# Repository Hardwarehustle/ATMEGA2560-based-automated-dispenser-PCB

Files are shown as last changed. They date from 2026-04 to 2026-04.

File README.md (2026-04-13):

# 💊 Automated Dispenser — ATMEGA2560 Based Smart Dispensing Controller PCB

> **Designed by:** Janardhan BV  
> **Tool:** EasyEDA  
> **MCU:** ATMEGA2560-16AU  
> **Date:** November 2024 | **Rev:** 1.0  
---

## 📌 Project Overview

This project is a **full-featured automated dispenser controller PCB** built around the **ATMEGA2560-16AU** (Arduino Mega 2560 compatible) microcontroller. The board is designed to drive **3 stepper motors** and **1 servo motor** for precise dispensing operations, with intelligent scheduling via a **real-time clock (RTC)**, remote alerting via a **SIM800L GSM module**, presence detection via an **IR sensor**, a **buzzer** for audio feedback, and an **I2C LCD display** for real-time status.

The system is ideal for **medicine dispensers, food dispensers, automated vending mechanisms**, or any time-triggered multi-compartment dispensing application.

The design covers:
- Full **schematic capture** in EasyEDA (ATMEGA2560-16AU + CH340G + all peripherals)
- **Multi-layer PCB layout** with 4x stepper/servo motor drives
- **GSM-based remote notification/control** via SIM800L
- **RTC-based scheduling** for timed dispensing events
- **Comprehensive GPIO breakout headers** for expansion
- **USB programming** via CH340G (Micro-USB)

---

## 🖼️ Project Visuals

### Schematic
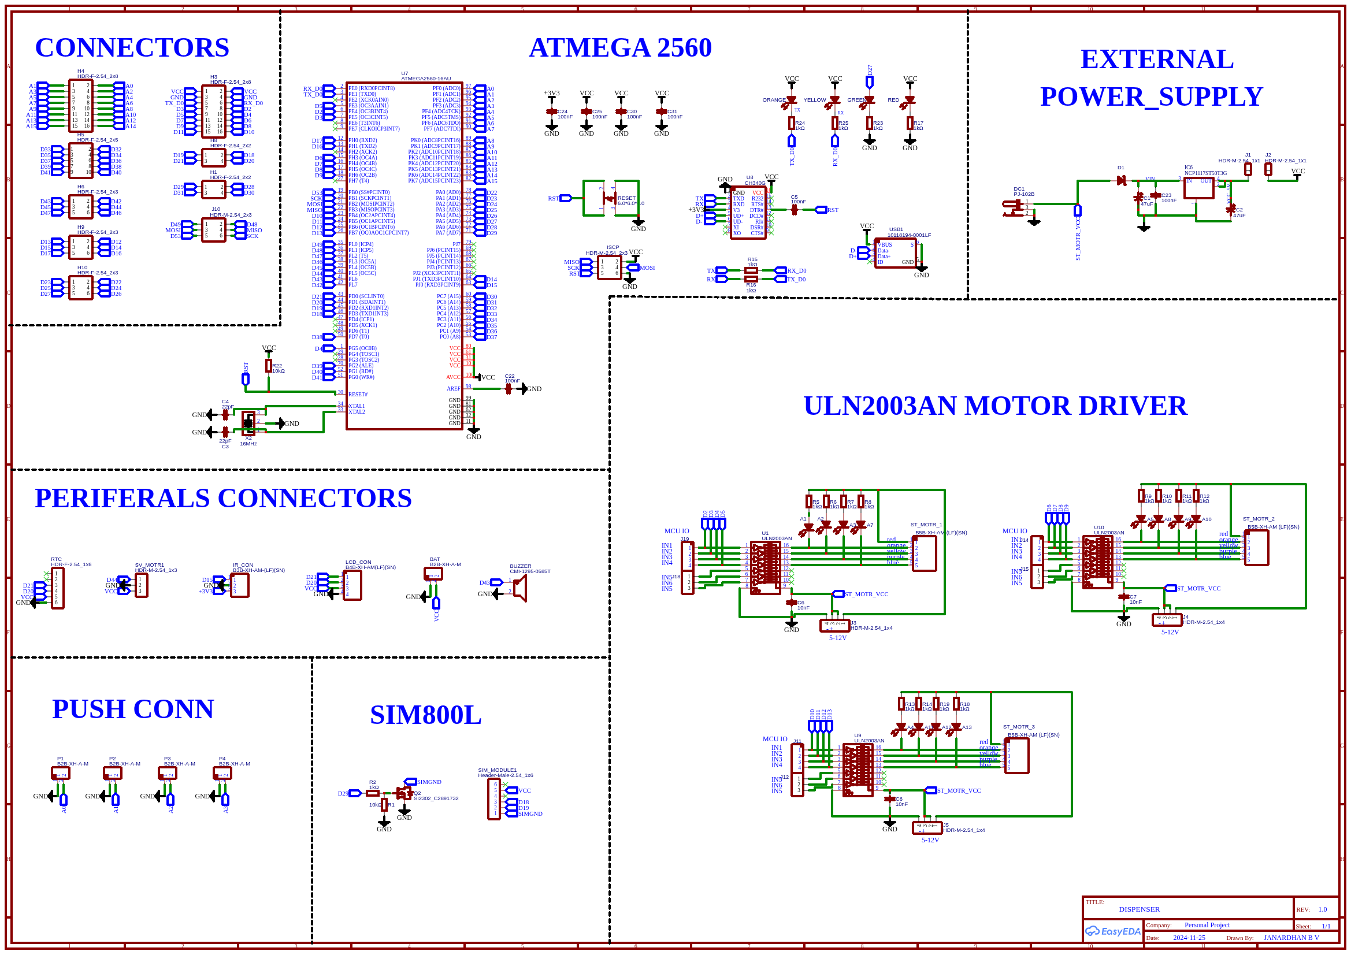
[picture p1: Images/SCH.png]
Schematic


### PCB Layout
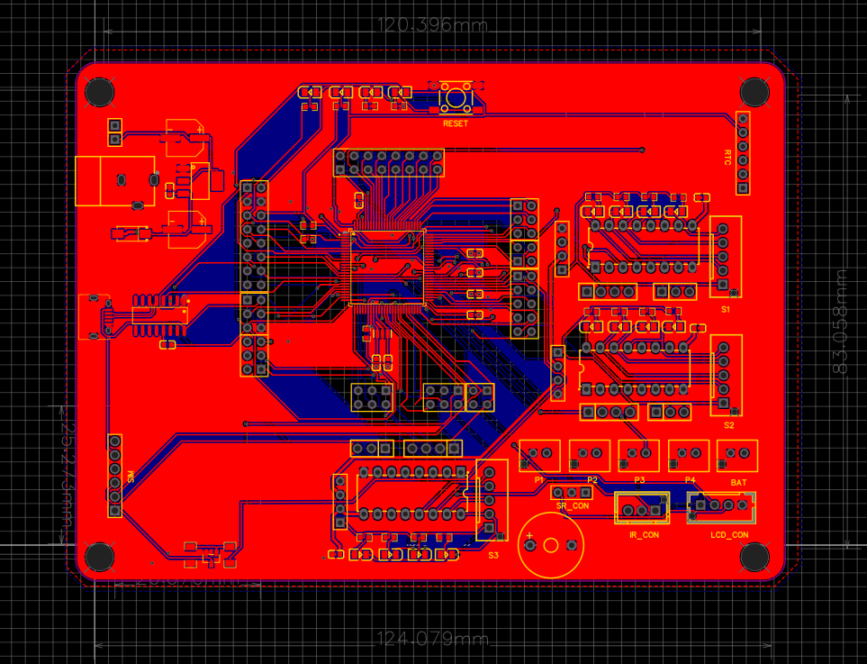
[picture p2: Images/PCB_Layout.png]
PCB Layout


### 3D Board Top View
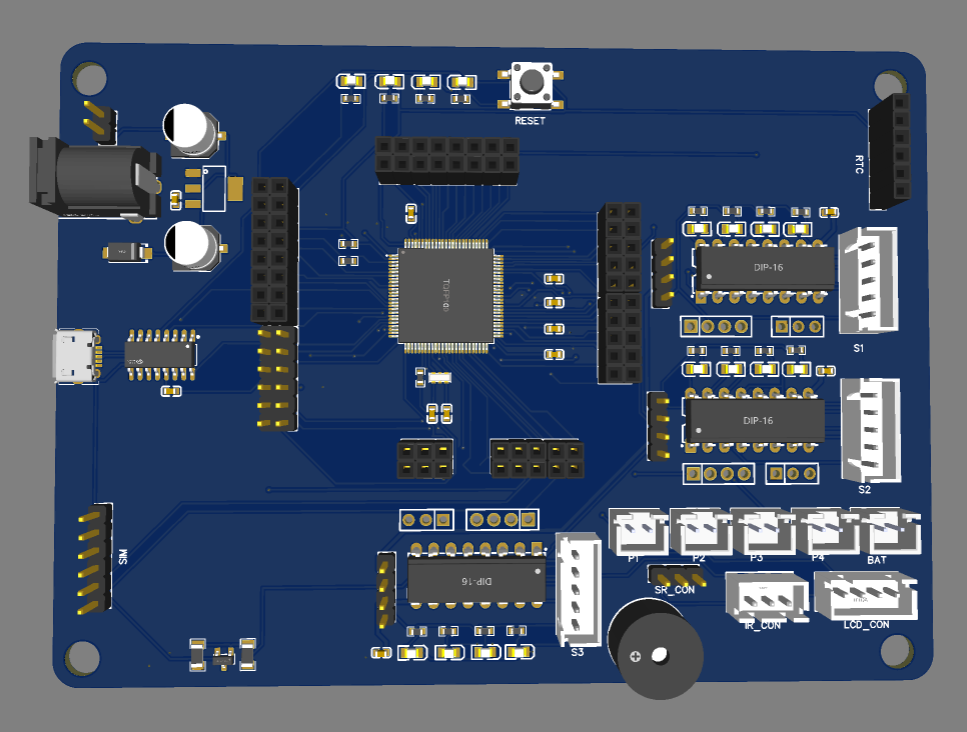
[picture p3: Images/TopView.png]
3D Top View


### 3D Board Bottom View
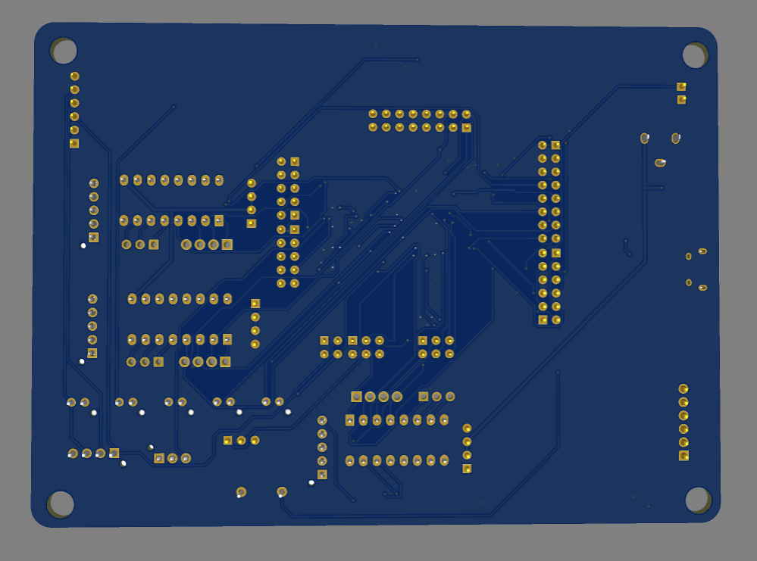
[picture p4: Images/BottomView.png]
3D Bottom View

---

## 🏗️ System Architecture

```
                         ┌────────────────────────┐
                         │    ATMEGA2560-16AU      │
    DC Power In ─────►  │  (Arduino Mega compat.) │◄──── USB (CH340G)
    (Barrel Jack)        │                         │
                         │  D2–D53 / A0–A15        │
                         └──────────┬──────────────┘
              ┌───────────┬─────────┼──────────────────────┐
              ▼           ▼         ▼                      ▼
     3x ULN2003AN      Servo    CH340G               SIM800L
     Stepper Drivers   Motor    (USB-UART)           (GSM Module)
     (ST_MOTR_1/2/3)  (D44)
              │                                           │
     3x Stepper                        ┌──────────────────┤
     Motors (28BYJ-48)                 ▼                  ▼
                                      RTC             IR Sensor
                                    (I2C)             (D15)
                                      │
                                      ▼
                                 LCD Display
                                  (I2C, 4-pin)
                                      │
                                   BUZZER (D43)
                                      │
                              4x Analog Sensors (P1–P4)
                              A0, A1, A2, A3
```

---

## 📊 Component BOM

### Core ICs

| Ref | Component | Value / Part | Function |
|:---:|:---|:---|:---|
| U7 | MCU | ATMEGA2560-16AU (TQFP-100) | Main microcontroller |
| U8 | USB-UART Bridge | CH340G | USB to serial for programming |
| U1, U9, U10 | Motor Driver | ULN2003AN (DIP-16) | Stepper motor driver (×3) |
| IC6 | LDO Regulator | NCP1117ST50T3G | 5V power regulator |
| Q2 | N-CH MOSFET | SI2302 (C2891732) | Motor power switching |

### Passive Components

| Ref | Value | Function |
|:---:|:---:|:---|
| R1 | 10 kΩ | SIM800L pull-up |
| R2 | 1 kΩ | SIM800L current limit |
| R5–R14, R18, R19 | 1 kΩ (×12) | LED current limiting resistors |
| R22 | 10 kΩ | RESET pull-up |
| R23–R25 | 1 kΩ | CH340G signal resistors |
| C1, C2 | 47 µF | Bulk supply decoupling |
| C3, C4 | 22 pF | MCU crystal load caps |
| C5 | 100 nF | Bypass cap |
| C6, C7, C8 | 10 nF | HF decoupling |
| C22–C25, C30, C31 | 100 nF | CH340G / MCU bypass caps |
| X2 | 16 MHz Crystal | CH340G oscillator |
| D1 | LED (×4) | Status LEDs: ORANGE, YELLOW, GREEN, RED |
| BUZZER | CMI-1295-0585T | Piezo buzzer for alerts (D43) |

---

## 🔌 Peripheral Connectors

| Connector | Type | Pins | Connected Signals |
|:---:|:---|:---:|:---|
| ST_MOTR_1 | B5B-XH 5-pin | 5 | Stepper Motor 1 coils (IN1–IN4 + GND) |
| ST_MOTR_2 | B5B-XH 5-pin | 5 | Stepper Motor 2 coils |
| ST_MOTR_3 | B5B-XH 5-pin | 5 | Stepper Motor 3 coils |
| SV_MOTR1 | HDR 3-pin | 3 | Servo Motor (D44, VCC, GND) |
| RTC | HDR-F 6-pin | 6 | I2C RTC Module (D20=SDA, D21=SCL) |
| SIM_MODULE1 | HDR 6-pin | 6 | SIM800L GSM Module (UART) |
| IR_CON | B3B-XH 3-pin | 3 | IR Sensor (+3V3, Signal D15, GND) |
| LCD_CON | B4B-XH 4-pin | 4 | I2C LCD (VCC, GND, D20, D21) |
| P1 | B2B-XH 2-pin | 2 | Analog Sensor 1 (A0, GND) |
| P2 | B2B-XH 2-pin | 2 | Analog Sensor 2 (A1, GND) |
| P3 | B2B-XH 2-pin | 2 | Analog Sensor 3 (A2, GND) |
| P4 | B2B-XH 2-pin | 2 | Analog Sensor 4 (A3, GND) |
| BAT | B2B-XH 2-pin | 2 | Battery Backup (VCC, GND) |
| DC1 | PJ-102B Barrel Jack | 3 | External DC Power Input |
| USB1 | Micro-USB | 5 | USB Programming / Power |

---

## 🎛️ GPIO Assignment Table

| Signal | ATMEGA2560 Pin | Function |
|:---|:---:|:---|
| TX / RX (USB) | PE0 / PE1 | CH340G UART Programming |
| D15 | PJ1 | IR Sensor Input |
| D20 (SDA) | PD1 | I2C — RTC + LCD |
| D21 (SCL) | PD0 | I2C — RTC + LCD |
| D43 | PL6 | Buzzer Output |
| D44 | PL5 | Servo Motor PWM |
| A0–A3 | PF0–PF3 | Analog Sensor Inputs (P1–P4) |
| ULN2003 IN1–IN4 (U1) | D2–D5 / D6–D9 | Stepper Motor 1 control |
| ULN2003 IN1–IN4 (U9) | — | Stepper Motor 3 control |
| ULN2003 IN1–IN4 (U10) | — | Stepper Motor 2 control |
| MOSI/MISO/SCK | PB2/PB3/PB1 | SPI / ICSP |
| D53 (SS) | PB0 | SPI Chip Select |

---

## ⚙️ Stepper Motor Driver — ULN2003AN

Three **ULN2003AN** Darlington transistor arrays drive three **28BYJ-48** unipolar stepper motors. [web:66] Each ULN2003AN handles 7 Darlington pairs, of which 4 are used per motor for the standard 4-phase coil sequence. [web:57] Motor supply is 5–12V via a dedicated `ST_MOTR_VCC` rail switched by the **SI2302 MOSFET (Q2)**.

```
ATMEGA2560 GPIO (IN1–IN4)  ──►  ULN2003AN  ──►  28BYJ-48 Stepper Motor
                                (500mA/ch)         (5V, 4-phase unipolar)
Step sequence: Blue→Pink→Yellow→Orange→Red
```

---

## 📡 GSM Module — SIM800L

The **SIM800L** connects via UART (Serial1) to the ATMEGA2560, enabling: [web:65]
- **Outbound SMS alerts** when dispensing occurs or errors are detected
- **Inbound SMS commands** to trigger manual dispensing remotely
- **GPRS data connectivity** for IoT logging (optional)

```
ATMEGA2560 (TX1/RX1) ──► SIM_MODULE1 header ──► SIM800L GSM Module
AT Command Interface  →  Quad-band 850/900/1800/1900 MHz
```

> ⚠️ SIM800L requires a **4.2V regulated supply at up to 2A peak** — a dedicated buck converter is recommended for the SIM module supply. [web:61]

---

## 🕐 RTC Module

The **RTC module** (e.g., DS3231 or DS1307) connects to the 6-pin RTC header over **I2C (D20/D21)**. It enables:
- Precise **time-triggered dispensing schedules** (morning/evening/custom)
- **Alarm interrupts** to wake the MCU from sleep for low-power operation
- Persistent timekeeping even during power cuts (battery-backed)

---

## 💡 Status LEDs

| LED Color | Signal | Purpose |
|:---:|:---:|:---|
| RED | A-series GPIO | Error / Fault indicator |
| ORANGE | A-series GPIO | Dispensing in progress |
| YELLOW | A-series GPIO | Low-level warning |
| GREEN | A-series GPIO | System OK / Ready |

All LEDs use **1kΩ current-limiting resistors** (R5–R14, R18, R19) to limit current to ~3.3mA per LED at 3.3V logic.

---

## 🔋 Power Architecture

```
External DC Input (Barrel Jack DC1)
   └──► NCP1117ST50T3G (5V LDO) ──► VCC (MCU, ICs, Peripherals)
                                 └──► ST_MOTR_VCC (Stepper supply via SI2302 MOSFET)
Micro-USB (USB1) ──► VBUS ──► CH340G + VCC (USB-powered mode)
BAT connector ──► Battery backup for RTC
```

---

## 📐 PCB Design Highlights

- **MCU:** ATMEGA2560-16AU TQFP-100 placed centrally
- **Motor Drivers:** U1, U9, U10 (ULN2003AN DIP-16) in IC sockets (S1, S2, S3) for replaceability
- **Bulk decoupling:** C1, C2 (47µF) + distributed 100nF ceramics near every IC
- **Crystal caps (C3, C4 = 22pF)** placed close to MCU XTAL pins
- **Reset button** (6×6×6mm tactile switch) accessible on top edge
- **ICSP header** (2×3, 2.54mm) for ISP programming fallback
- **SPI header (J10)** for external SPI peripherals
- **Comprehensive GPIO breakout headers** (H1–H10) exposing all digital and analog pins
- **SIM800L header** on left edge for direct module stacking

---

## 🧪 Bring-Up & Testing Procedure

### Step 1 — Power Supply Check
- Apply 7–12V DC to DC1 (barrel jack)
- Verify NCP1117ST50T3G output: **+5.0V** on VCC net
- Measure current draw in idle: ~80–120 mA (MCU + CH340G)

### Step 2 — USB Enumeration
- Connect Micro-USB to PC
- CH340G should enumerate as a **COM port** (Windows) or `/dev/ttyUSB0` (Linux)
- Upload a blink sketch via Arduino IDE (select **Arduino Mega 2560**)

### Step 3 — Stepper Motor Test
- Connect 28BYJ-48 motors to ST_MOTR_1/2/3
- Run 4-phase step sequence on each ULN2003AN
- Verify smooth rotation without stalling

### Step 4 — RTC Module Test
- Connect DS3231 to RTC header
- Read/write time via I2C (D20/D21)
- Confirm timekeeping accuracy over 24 hours

### Step 5 — GSM Module Test
- Insert SIM card into SIM800L
- Send AT command via Serial: `AT` → expect `OK`
- Send SMS: `AT+CMGS="+91XXXXXXXXXX"` → verify delivery

### Step 6 — Full System Integration
- Program dispensing schedule in RTC
- Verify stepper triggers at correct times
- Confirm SMS alert on dispensing event
- Test IR sensor presence detection and buzzer feedback

---

## 🖥️ Software / Firmware Stack

```
Libraries Required (Arduino IDE):
├── Wire.h              — I2C (RTC + LCD)
├── RTClib.h            — DS1307 / DS3231 RTC
├── LiquidCrystal_I2C.h — I2C LCD display
├── Stepper.h / AccelStepper.h  — Stepper motor control
├── Servo.h             — Servo motor (D44)
└── SoftwareSerial.h    — SIM800L UART communication
```

---

## 📁 Repository Structure

```
Automated-Dispenser/
├── images/
│   ├── TopView.jpg                          ← 3D board render
│   └── Schematic_Dispenser_project.pdf      ← Full schematic
├── Firmware/
│   └── dispenser_main/
│       └── dispenser_main.ino               ← Arduino sketch
├── Gerber/
│   └── (Gerber files for PCB fabrication)
├── BOM/
│   └── BOM_Dispenser.csv
└── README.md
```

---

## 🏷️ GitHub Topics to Add

```
atmega2560  arduino-mega  dispenser  stepper-motor  uln2003
sim800l  gsm  rtc  pcb-design  easyeda  automation  iot
28byj-48  i2c-lcd  embedded-hardware
```

---

## ⚠️ Design Notes & Cautions

- **ULN2003AN DIP-16 ICs** are in sockets — easy to replace if burned
- **SI2302 MOSFET (Q2)** switches stepper motor supply — ensure gate drive from MCU is sufficient (3.3V logic may need a pull-up for full enhancement)
- **SIM800L needs ~2A peak current** — use a dedicated 4.2V/2A supply, not the onboard 5V LDO
- **Crystal load capacitors (C3, C4 = 22pF)** must be placed within 5mm of MCU XTAL pins to avoid oscillation failure
- **RTC battery** (CR2032) should be connected to BAT connector for timekeeping during power loss

---

## 📄 License

This project is open for educational and personal use.  
© 2024 Janardhan BV — All rights reserved.

---

## 🙋 Author

**Janardhan BV**  
Embedded Hardware Engineer | PCB Design | Power Electronics  
📍 Bengaluru, India

---
*Designed in EasyEDA | ATMEGA2560 Automated Dispenser — Personal Project*

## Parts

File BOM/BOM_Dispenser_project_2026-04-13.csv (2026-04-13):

ID | Name | Designator | Footprint | Quantity | Manufacturer Part | Manufacturer | Supplier | Supplier Part | Price | Pins | 3DModel | Contributor | JLCPCB Part Class | image | link
1 | CMI-1295-0585T | BUZZER | BUZ-TH_BD12.0-P7.60-D0.6-FD | 1 | CMI-1295-0585T | CUI | LCSC | C22359712 | 0.853 | 2 | BUZ-TH_D12.0-H9.5-P7.60 | lcsc | Extended Part |  | https://item.szlcsc.com/200842.html
2 | SI2302_C2891732 | Q2 | SOT-23-3_L2.9-W1.3-P1.90-LS2.4-BR | 1 | SI2302 | YONGYUTAI(永裕泰) | LCSC | C2891732 | 0.012 | 3 | SOT-23-3P_L2.9-W1.3-H1.0-LS2.4-P0.95 | LCSC | Extended Part |  | https://www.diodes.com/assets/Package-Files/SOT23.pdf
3 | 10kΩ | R1 | R1206 | 1 | 1206W4F1002T5E | UNI-ROYAL(厚声) | LCSC | C17902 | 0.005 | 2 | R1206_L3.2-W1.6-H0.6 | lcsc | Basic Part |  | https://item.szlcsc.com/311874.html
4 | 1kΩ | R2 | R1206 | 1 | 1206W4F1001T5E | UNI-ROYAL(厚声) | LCSC | C4410 | 0.004 | 2 | R1206_L3.2-W1.6-H0.6 | lcsc | Basic Part |  | https://item.szlcsc.com/311874.html
5 | B2B-XH-A-M | BAT,P1,P2,P3,P4 | CONN-TH_B2B-XH-A-M | 5 | B2B-XH-A-MB2P-VH（SMT业务专用） | JST | LCSC | C2683608 | 0.049 | 2 | CONN-TH_B2B-XH-A-M | LCSC | Extended Part |  | https://item.szlcsc.com/2780587.html
6 | HDR-M-2.54_1x4 | J3,J4,J5 | HDR-M-2.54_1X4 | 3 |  |  | LCSC | C124378 | 0.055 | 4 | HDR-M-2.54_1x4 | LCEDA_Lib
7 | HDR-F-2.54_2x8 | H4,H3 | HDR-F-2.54_2X8 | 2 |  |  | LCSC | C30734 | 0.142 | 16 | HDR-F-2.54_2x8 | LCEDA_Lib
8 | HDR-F-2.54_2x5 | H5 | HDR-F-2.54_2X5 | 1 |  |  | LCSC | C30419 | 0.062 | 10 | HDR-F-2.54_2x5 | LCEDA_Lib
9 | HDR-F-2.54_2x3 | H6,H9,H10 | HDR-F-2.54_2X3 | 3 |  |  | LCSC | C65114 | 0.044 | 6 | HDR-F-2.54_2x3 | LCEDA_Lib
10 | HDR-F-2.54_2x2 | H1,H8 | HDR-F-2.54_2X2 | 2 |  |  | LCSC | C239342 | 0.086 | 4 | HDR-F-2.54_2x2 | LCEDA_Lib
11 | 10nF | C6,C7,C8 | C0603 | 3 | GRM188R71H103KA01D | muRata(村田) | LCSC | C77053 | 0.005 | 2 | C0603_L1.6-W0.8-H0.8 | lcsc | Extended Part |  | https://item.szlcsc.com/362304.html
12 | 100nF | C5,C22,C23,C24,C25,C30,C31 | C0603 | 7 | CC0603KRX7R8BB104 | YAGEO(国巨) | LCSC | C92490 | 0.003 | 2 | C0603_L1.6-W0.8-H0.8 | lcsc | Extended Part |  | https://item.szlcsc.com/362304.html
13 | ULN2003AN | U1,U9,U10 | DIP-16_16P-L20.2-W6.6-P2.54-LS7.6-BL | 3 | ULN2003AN | TI(德州仪器) | LCSC | C90448 | 0.473 | 16 | DIP-16_L20.0-W6.4-H3.5-LS7.62-P2.54 | 立创EDA官方封装库 | Extended Part |  | https://item.szlcsc.com/49975.html
14 | 22pF | C3,C4 | C0603 | 2 | CC0603JRNPO9BN220 | YAGEO(国巨) | LCSC | C105620 | 0.003 | 2 | C0603_L1.6-W0.8-H0.8 | lcsc | Extended Part |  | https://item.szlcsc.com/362304.html
15 | B3B-XH-AM-(LF)(SN) | IR_CON | CONN-TH_3P-P2.50_B3B-XH-AM-LF-SN | 1 | B3B-XH-AM(LF)(SN) | JST | LCSC | C161870 | 0.095 | 3 | CONN-TH_XH2.50-LI-3P | LCSC | Extended Part |  | https://lcsc.com/product-detail/Wire-To-Board-Wire-To-Wire-Connector_JST-Sales-America_B3B-XH-AM-LF-SN_JST-Sales-America-B3B-XH-AM-LF-SN_C161870.html
16 | HDR-M-2.54_1x1 | J1,J2 | HDR-M-2.54_1X1 | 2 |  |  | LCSC | C81276 | 0.014 | 1 | HDR-M-2.54_1x1 | LCEDA_Lib
17 | B4B-XH-AM(LF)(SN) | LCD_CON | CONN-TH_B4B-XH-AM-LF-SN | 1 | B4B-XH-AM(LF)(SN) | JST | LCSC | C161871 | 0.106 | 4 | CONN-TH_XH2.50-LI-4P | LCSC | Extended Part |  | https://atta.szlcsc.com/upload/public/pdf/source/20180319/1BDBE0A1D3E09F819A9E3600059072E6.pdf
18 | HDR-F-2.54_1x6 | RTC | HDR-F-2.54_1X6 | 1 |  |  | LCSC | C40877 | 0.088 | 6 | HDR-F-2.54_1x6 | LCEDA_Lib
19 | HDR-M-2.54_1x3 | SV_MOTR1 | HDR-M-2.54_1X3 | 1 |  |  | LCSC | C180248 | 0.211 | 3 | HDR-M-2.54_1x3 | LCEDA_Lib
20 | GREEN | A1,A2,A3,A4,A5,A7,A8,A9,A10,A11,A12,A13,GREEN,ORANGE,RED,YELLOW | LED0805-R-RD | 16 | KT-0805翠绿 | KENTO | LCSC | C2297 | 0.016 | 2 | LED0805-RD | lcsc | Basic Part |  | https://item.szlcsc.com/88042.html
21 | HDR-M-2.54_2x3 | ISCP,J10 | HDR-M-2.54_2X3 | 2 |  |  | LCSC | C65114 | 0.044 | 6 | HDR-M-2.54_2x3 | LCEDA_Lib
22 | 1kΩ | R5,R6,R7,R8,R9,R10,R11,R12,R13,R14,R18,R19,R15,R16,R17,R23,R24,R25 | R0603 | 18 | RC0603FR-071KL | YAGEO(国巨) | LCSC | C22548 | 0.002 | 2 | R0603 | lcsc | Extended Part |  | https://www.mouser.in/datasheet/2/447/PYu_RT_1_to_0_01_RoHS_L_11-1669912.pdf
23 | PJ-102B | DC1 | DC-IN-TH_PJ-102B | 1 | PJ-102B | CUI | LCSC | C22359713 | 0.699 | 3 | DC-IN-TH_PJ-102B | lcsc | Extended Part |  | https://atta.szlcsc.com/upload/public/pdf/source/20240314/7ACA70A53C555A4711BC0A05F40D0AE5.pdf
24 | 47uF | C1,C2 | CAP-SMD_BD6.3-L6.6-W6.6-FD-A | 2 | VZT470M1HTR-0606 | lelon(立隆) | LCSC | C688950 | 0.098 | 2 | CAP-SMD_BD6.3-L6.6-W6.6-FD-A | LCSC | Extended Part |  | https://atta.szlcsc.com/upload/public/pdf/source/20181114/C278512_F6ABFFB833591ACF6A4B64AEC8B9747F.pdf
25 | SS54_C22452 | D1 | SMA_L4.4-W2.8-LS5.4-R-RD | 1 | SS54 | MDD | LCSC | C22452 | 0.036 | 2 | SMA_L4.4-W2.8-LS5.4-R-RD | 立创EDA官方封装库 | Basic Part |  | https://item.szlcsc.com/310096.html
26 | NCP1117ST50T3G | IC6 | SOT223 | 1 |  |  |  |  |  | 4
27 | Header-Male-2.54_1x4 | J11,J14,J19 | DIP-1X4P-2.54MM-M | 3 | 210S-1*4P L=11.6MMGold-plated black | Ckmtw | LCSC | C124378 | 0.055 | 4 |  | LCSC
28 | Header-Male-2.54_1x3 | J12,J15,J18 | DIP-1X3P-2.54MM-M | 3 | Header2.54mm 1*3P | BOOMELE | LCSC | C49257 | 0.021 | 3 |  | LCSC |  | //image.lceda.cn/szlcsc/C49257.jpg
29 | 10kΩ | R22 | R0603 | 1 | RC0603FR-0710KL | YAGEO(国巨) | LCSC | C98220 | 0.002 | 2 | R0603 | lcsc | Extended Part |  | https://www.mouser.in/datasheet/2/447/PYu_RT_1_to_0_01_RoHS_L_11-1669912.pdf
30 | 6.0*6.0*6.0 | RESET | SW-SMD_4P-L6.0-W6.0-P4.50-LS8.6 | 1 | 6.0*6.0*6.0 | BOOMELE(博穆精密) | LCSC | C5127964 | 0.022 | 4 | SW-SMD_4P-L6.0-W6.0-P4.50-LS8.6 | lcsc | Extended Part |  | https://item.szlcsc.com/2796384.html
31 | B5B-XH-AM (LF)(SN) | ST_MOTR_1,ST_MOTR_2,ST_MOTR_3 | CONN-TH_B5B-XH-AM-LF-SN | 3 | B5B-XH-AM(LF)(SN) | JST | LCSC | C161872 | 0.119 | 5 | CONN-TH_B5B-XH-AM (LF)(SN) | LCSC | Extended Part |  | https://atta.szlcsc.com/upload/public/pdf/source/20180319/3CD633800A52712ED01B88FEDB4D2297.pdf
32 | ATMEGA2560-16AU | U7 | TQFP-100_L14.0-W14.0-P0.50-LS16.0-BL | 1 | ATMEGA2560-16AU | MICROCHIP(美国微芯) | LCSC | C22460 | 13.713 | 100 | TQFP-100_L14.0-W14.0-H1.2-LS16.0-P0.50 | lcsc | Extended Part |  | https://item.szlcsc.com/401076.html
33 | CH340G | U8 | SOIC-16_L9.9-W3.9-P1.27-LS6.0-BL | 1 | CH340G | WCH(南京沁恒) | LCSC | C14267 | 0.554 | 16 | SOIC-16_L9.9-W3.9-H1.8-LS6.0-P1.27 | lcsc | Extended Part |  | http://datasheet.octopart.com/MC14076BDR2G-ON-Semiconductor-datasheet-608107.pdf
34 | 10118194-0001LF | USB1 | MICRO-USB-SMD_10118194-0001LF | 1 | 10118194-0001LF | Amphenol | LCSC | C132563 | 0.21 | 9 | MICRO-USB-SMD_10118194-0001LF | LCSC | Extended Part |  | https://item.szlcsc.com/143863.html
35 | 16MHz | X2 | OSC-SMD_3P-L3.2-W1.3-P0.95-L | 1 | CSTCE16M0V53-R0 | muRata(村田) | LCSC | C32180 | 0.231 | 3 | OSC-SMD_3P-L3.2-W1.3-H0.8-P0.95 | 立创EDA官方封装库 | Extended Part |  | https://item.szlcsc.com/33143.html

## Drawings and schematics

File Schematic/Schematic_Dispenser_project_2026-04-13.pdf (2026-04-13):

# ATMEGA 2560D² D³ D⁴ D⁵

# EXTERNAL

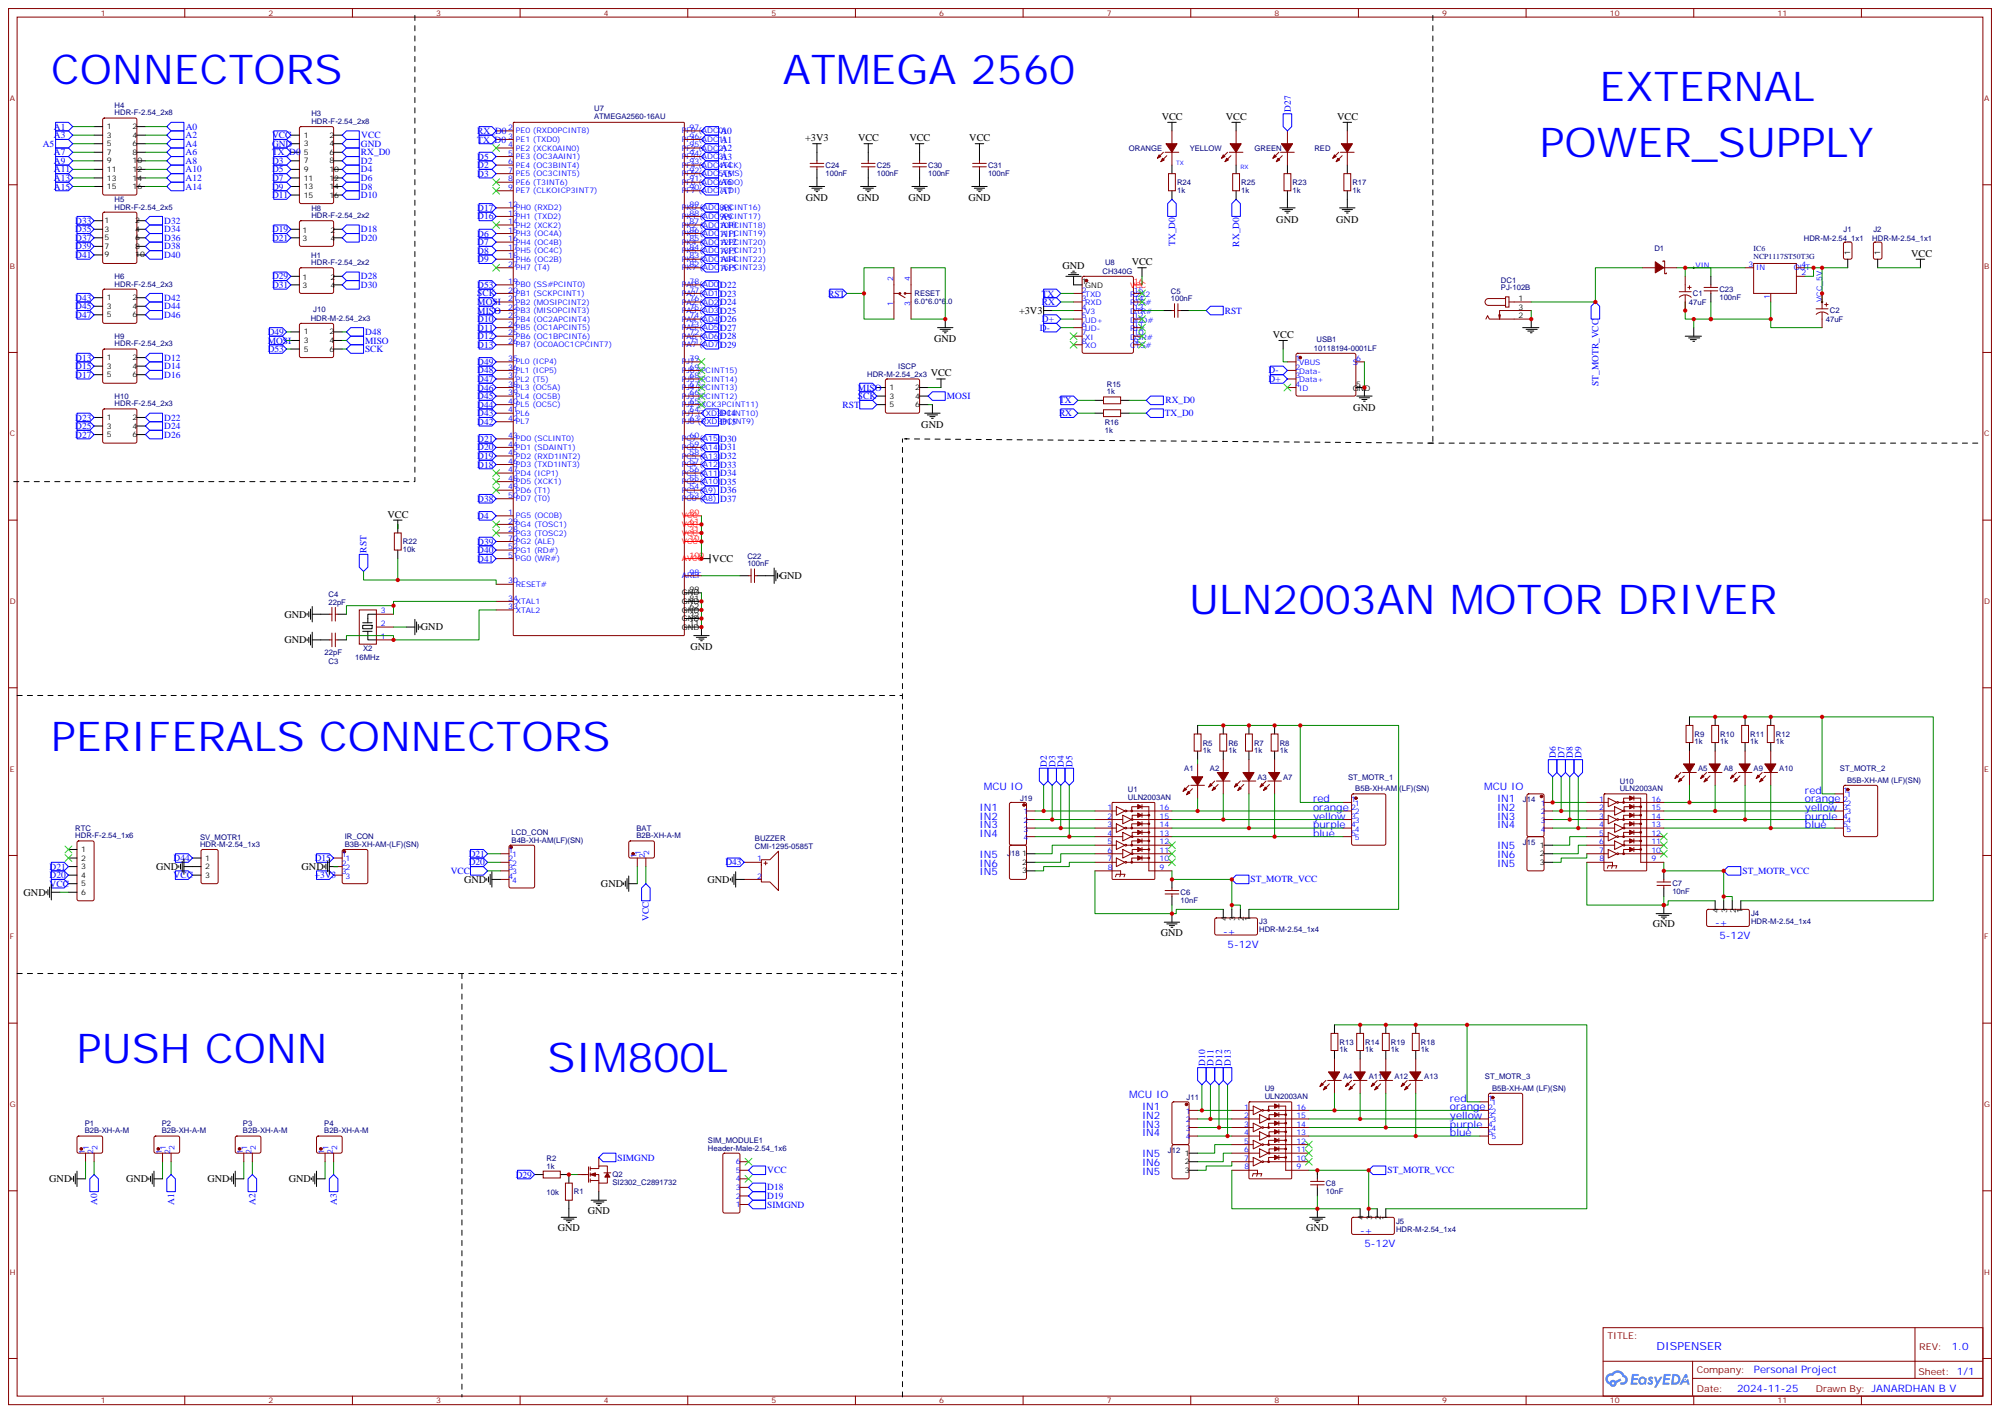
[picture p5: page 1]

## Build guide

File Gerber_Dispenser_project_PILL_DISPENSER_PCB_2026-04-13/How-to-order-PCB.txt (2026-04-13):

How to Order PCB

Please refer to:
https://docs.easyeda.com/en/PCB/Order-PCB
